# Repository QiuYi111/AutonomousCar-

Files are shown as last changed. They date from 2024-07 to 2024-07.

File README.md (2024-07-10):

# 机电系统设计实践

Openmv 官方中文教程 https://book.openmv.cc/

STM32教程https://ucbeginner.com/stm32cubeide/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,Best%20Practices%20...%208%20Troubleshooting%20...%20More%20items

git 官方中文教程 https://git-scm.com/book/zh/v2

STM32 油管系列教程
STM32教程 (https://www.youtube.com/watch?v=Hffw-m9fuxc "STM32教程")

电气原理图绘制工具 https://www.diagrams.net/index.html

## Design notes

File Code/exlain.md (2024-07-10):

好的，这段代码主要实现了通过OpenMV相机进行目标检测和跟踪，并通过UART串口与STM32单片机通信，以实现控制LED灯、舵机和其他功能。以下是这段代码的详细中文解释：

### 导入模块
```python
import sensor, image, time, math, pyb, time
from pyb import LED, UART, Servo, Pin, Timer
import json
import ustruct
```
这些模块用于控制传感器、处理图像、计时、数学计算、控制硬件等。

### 初始化UART串口
```python
uart = UART(3,115200)   # 定义串口3变量
uart.init(115200, bits=8, parity=None, stop=1) # 使用给定参数初始化
```
初始化UART串口，用于与STM32单片机通信。

### 初始化全局变量
```python
rx_buff = []
state = 0
MODE = 0
rx_buff1 = []
state1 = 0
is_fetch1 = 0
red_led = LED(1)
```
这些全局变量用于串口通信的数据缓冲、状态和模式管理。

### 初始化LED灯
```python
led1 = pyb.LED(1)
led2 = pyb.LED(2)
led3 = pyb.LED(3)
```
初始化三个LED灯，用于指示系统状态。

### 串口接收函数
```python
def Receive_Prepare1(data):
    global state
    global MODE
    if state == 0:
        if data == 0xb3:
            state = 1
        else:
            state = 0
            rx_buff.clear()
    elif state == 1:
        MODE = data
        print(MODE)
        state = 2
    elif state == 2:
        if data == 0xb4:
            state = 3
    else:
        state = 0
        rx_buff.clear()
```
这个函数用于处理串口接收到的数据，根据接收到的字节调整状态和模式。

```python
def Receive_Prepare2(data1):
    global state1
    global is_fetch1
    if state1 == 0:
        if data1 == 0xa0:  # 帧头0xb3
            state1 = 1
        else:
            state1 = 0
            rx_buff1.clear()
    elif state1 == 1:
        is_fetch1 = data1
        print(is_fetch1)
        state1 = 2
    elif state1 == 2:
        if data1 == 0xa1:  # 0xb4
            state1 = 3
        else:
            state1 = 0
            rx_buff1.clear()
```
这个函数处理另一种串口数据，用于不同的状态和数据处理。

### 主循环
```python
mode = 2
while(True):
    red_led.on()
    if MODE == 0:  # 等待STM32发送指令
        if (uart.any() > 0):
            c = uart.readchar()
            Receive_Prepare1(c)
            print(MODE)
```
这是主循环，控制不同模式下的操作。当`MODE`为0时，等待STM32发送指令。

### 循迹模式
```python
    if MODE == 1:  # 循迹部分
        print('MODE==1')
        if mode == 2:
            sensor.reset()  # 初始化摄像头传感器
            sensor.set_pixformat(sensor.RGB565)
            sensor.set_framesize(sensor.QQVGA)
            sensor.skip_frames(10)
            sensor.set_auto_gain(False)  # 颜色跟踪必须关闭自动增益
            sensor.set_auto_whitebal(False)  # 颜色跟踪必须关闭白平衡
            clock = time.clock()
            # a=0
            # 串口接收函数2
            # rx_buff=[
```
当`MODE`为1时，进入循迹模式，初始化摄像头传感器和一些图像处理设置。

```python
            while(mode == 2):
                def find_max(blobs):
                    max_size = 0
                    for blob in blobs:
                        if blob.pixels() > max_size:
                            max_blob = blob
                            max_size = blob.pixels()
                    return max_blob  # 寻找最大色块并返回最大色块的坐标
                img = sensor.snapshot().lens_corr(strength = 1.8, zoom = 1.0)
                wuti_threshold = (0, 100, 9, 127, 0, 127)
                blobs = img.find_blobs([wuti_threshold])
                if blobs:
                    max_blob = find_max(blobs)
                    img.draw_rectangle(max_blob.rect())  # 框选最大色块
                    img.draw_cross(max_blob.cx(), max_blob.cy())  # 在最大色块中心画十字
                    pcx = max_blob.cx() - 79.5  # 定义pcx为最大色块中心的横坐标
                    pcy = 119 - max_blob.cy()
                    if pcy > 90:
                        dev_s1 = 90
                    else:
                        dev_s1 = pcy
                    if pcx < 0:
                        cy1 = 1
                    else:
                        cy1 = 0
                    cw1 = int(abs(pcx))
                    cx1 = int(abs(pcx * 10)) % 10
                    ch1 = int(dev_s1)
                    OUT_DATA1 = bytearray([0x2C, 0x12, cy1, cw1, cx1, ch1, 0x5B])
                    uart.write(OUT_DATA1)
                    # print(pcx)
                    print(pcy)
                else:
                    OUT_DATA2 = bytearray([0x2C, 0x12, 0, 9, 9, 90, 0x5B])  # 原地缓慢旋转
                    # print(OUT_DATA2)
                    uart.write(OUT_DATA2)
                    # print('not found!')
```
在这个循环中，摄像头捕捉图像并寻找符合阈值的色块，找到后框选最大色块并发送其坐标数据到STM32。

### 模式切换
```python
                if (uart.any() > 0):
                    cc = uart.readchar()
                    Receive_Prepare2(cc)
                if is_fetch1 == 1:
                    mode = 6
                    print('mode=6')
```
如果接收到特定数据，会切换模式。

### 其他模式处理
```python
        if mode == 3:
            LED(1).on()
            LED(2).on()
            LED(3).on()
            s1 = Servo(1)  # P7
            s1.angle(-30)
            sensor.reset()  # 重置并初始化传感器
            sensor.set_pixformat(sensor.GRAYSCALE)  # 设置像素格式为灰度图像
            sensor.set_framesize(sensor.QQVGA)  # 设置帧大小为QVGA (320x240)
            THRESHOLD = (80, 255)
            sensor.skip_frames(time=20)  # 等待设置生效
            clock = time.clock()  # 创建时钟对象以跟踪FPS
            comp = 0
            startsym = 1
            dist = 0
            chan = 0
            mark1 = 0
            mark2 = 0
            # mark3=0
```
不同的模式下，进行不同的初始化和处理，比如模式3中，初始化舵机、传感器等，并进行相应的图像处理和数据传输。

### 避障模式
```python
    elif MODE == 2:  # 避障部分
        if mode == 2:
            LED(1).on()
            LED(2).on()
            LED(3).on()
            sensor.reset()  # 初始化摄像头传感器
            sensor.set_pixformat(sensor.RGB565)
            sensor.set_framesize(sensor.QQVGA)
            sensor.skip_frames(10)
            # sensor.set_auto_whitebal(False)
            clock = time.clock()
            # 串口接收函数2
            rx_buff = []
            def Receive_Prepare2(data):
                global state
                global is_fetch
                if state == 0:
                    if data == 0xaa:  # 帧头0xb3
                        state = 1
                    else:
                        state = 0
                        rx_buff.clear()
                elif state == 1:
                    is_fetch = data
                    print(is_fetch)
                    state = 2
                elif state == 2:
                    if data == 0xdd:  # 0xb4
                        state = 3
                else:
                    state = 0
                    rx_buff.clear()
```
在避障模式下，摄像头捕捉图像并寻找红色阈值的色块，找到后框选最大色块并发送其坐标数据到STM32。

### 其他模式处理
代码中还包含了模式5和模式6的处理，这些模式下进行了不同的传感器初始化和图像处理，以实现不同的功能需求。

### 总结
这段代码通过OpenMV相机进行目标检测和跟踪，并通过UART串口与STM32单片机通信，来实现不同模式下

的功能，例如循迹、避障等。不同的模式下进行了不同的传感器初始化和图像处理，以实现特定的功能需求。

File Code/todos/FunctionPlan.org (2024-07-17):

* DONE MeasureDistance函数
** 参数
   + TIM_HandelDef 定时器
   + Trig 的port 和引脚号
   + Echo的port和引脚号
** 返回
   + uint16_t 障碍物距离信息。单位mm

* TODO imuTheta
** 参数
   +
** 返回
   + 偏航角信息

* TODO imuAcc
** 参数
   +
** 返回
   + 各方向加速度

* TODO motorController
** 参数
   + 指定轮速
   + KP,KI,KD
** 返回
   + void 控制PWM占空比

* TODO lineFollowing
**   
** 返回
   + 两轮差速

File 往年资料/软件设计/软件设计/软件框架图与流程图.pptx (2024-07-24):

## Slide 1

系统软件逻辑框图

执行模块

motor.h
motor.c
控制电机转速
读取电机参数

bluetooth.h
bluetooth.c
与外部设备交换数据
接收外部设备指令

imu.h
imu.c
获得小车当前方向与位置信息

sonic.h
sonic.c
控制超声波探测器测距
发送测得参数

control.h
control.c
PID计算与控制
电机速度设定
小车方向设定

main.c
主函数
收发/传输数据
接受/发出指令

servo.h
servo.c
控制舵机旋转
获得舵机转角

openmv.py
处理openmv感知到的图像
计算得出进一步指令需要的参数
发送参数（抓取物体位置、巡线等）

openmv.h
openmv.c
处理与openmv的数据通讯
与单片机传输openmv得到的参数与指令

信息采集模块

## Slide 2

巡线部分算法

openmv
拍摄图像

检测特定行中白色块数

二值化处理

2个
取中心点前进

非2个（0，1，3，4等）
根据前几次搜索结果进行偏移

滤波去噪

根据偏移量PID调速

调用卸货模块

搜索特定行

NO

检测是否到达终点

结 束

YES

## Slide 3

巡线软件逻辑框图

openmv.py
处理openmv感知到的图像
计算得出进一步指令需要的参数
发送参数（抓取物体位置、巡线等）

偏移量等路线信息

openmv.h
openmv.c
处理与openmv的数据通讯
与单片机传输openmv得到的参数与指令

main.c
主函数
收发/传输数据
接受/发出指令

control.h
control.c
PID计算与控制
电机速度设定
小车方向设定

motor.h
motor.c
控制电机转速
读取电机参数

设定转速等

传输数据

发送运动指令

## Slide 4

避障部分算法

开 始

利用超声传感器测距

检测是否小于规定距离

算法仿真如下

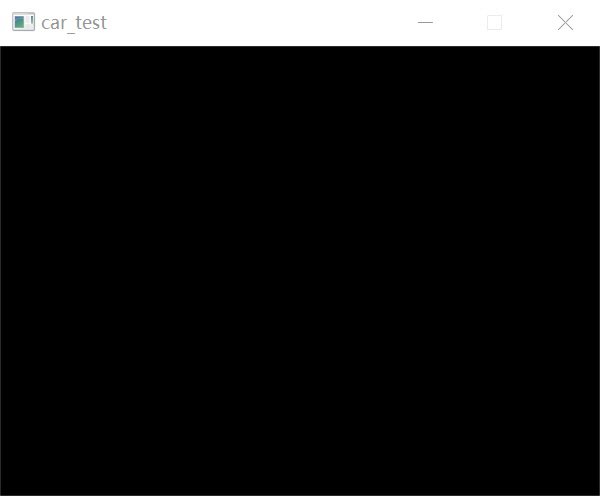
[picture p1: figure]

NO

YES

利用势场法确定新方向

检测是否到达终点

调用卸货模块

NO

结 束

YES

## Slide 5

避障软件逻辑框图

imu.h
imu.c
获得小车当前方向与位置信息

main.c
主函数
收发/传输数据
接受/发出指令

control.h
control.c
PID计算与控制
电机速度设定
小车方向设定

motor.h
motor.c
控制电机转速
读取电机参数

设定转速等

发送运动指令

sonic.h
sonic.c
控制超声波探测器测距
发送测得参数

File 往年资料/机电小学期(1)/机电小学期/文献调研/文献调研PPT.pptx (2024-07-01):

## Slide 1

机电系统设计实践课程初期汇报

机电系统初探

文献调研与初步方案

汇报人：荆尹浩宇 张佳悦 滕一铭

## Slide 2

目录

CONTENTS

01

车体结构

02

功能传感

03

驱动控制

04

电机电源

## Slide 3

PART 01

车体结构

·车架总体 ·抓取机构

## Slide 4

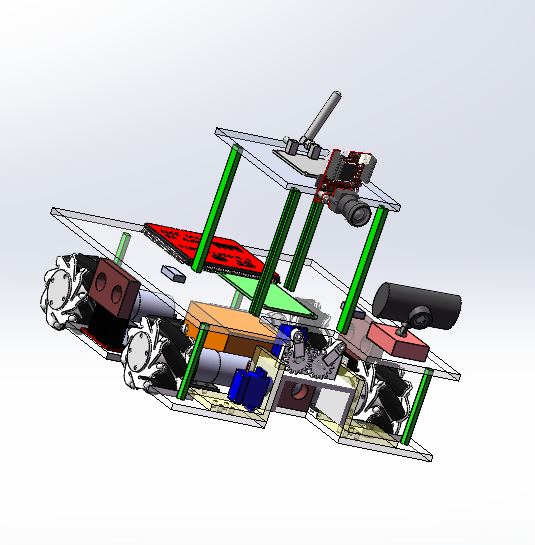
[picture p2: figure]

车架总体

车架整体尺寸需求：
在自助避障任务中，障碍物间的间距不小于350mm，因此，小车的宽度应小于350mm并留出适量裕度。

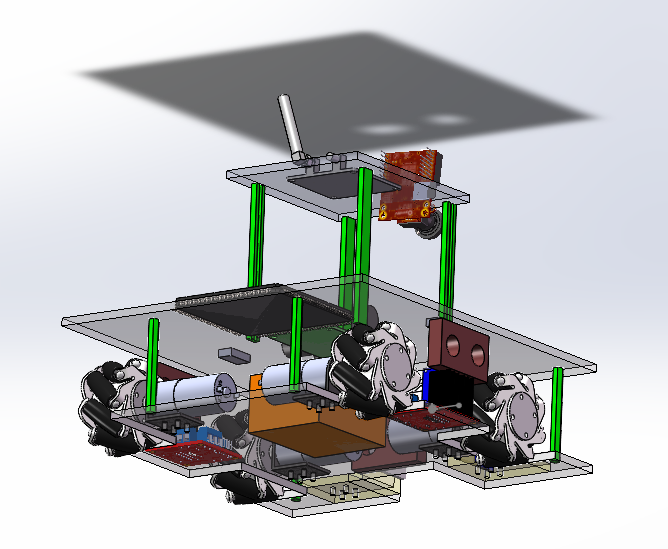
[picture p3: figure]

初步建模

由于小车的占地面积不能过大，且需要在车架上装配多种元器件和电子线路，因此可以考虑将小车做成 二层或三层结构。

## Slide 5

车架总体

轮式小车

节省空间、机动性好
承载重量大、结构简单
可控性强、安全性好

履带式小车

对地面单位压力小
行驶通过能力强
结构简单，结实耐用
适合在条件不好的环境下作业

步行式机器人

对地形适应性较强
对环境的破坏程度较小
运动的灵活性强
运动控制较为精确

A

B

C

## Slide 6

抓取机构

抓取机构尺寸需求：
货物直径30mm，高40mm，重50g。因此抓取装置的“钳爪”需要和货物尺寸匹配，同时要考虑抓取时的姿态，保证足够的压力与摩擦力，避免抓取过程中掉落。

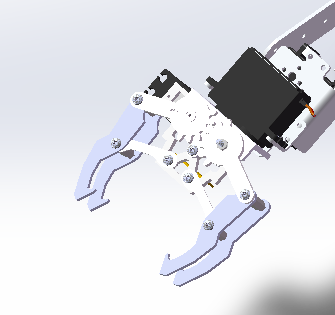
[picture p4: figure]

初步建模

考虑到取物前后图像识别的需要，以及超声波传感器的位置，需要使抓取结构尽量短小，且抓取后不能遮挡摄像头与传感器

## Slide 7

抓取机构

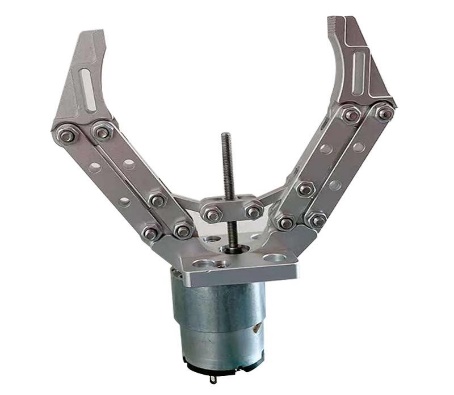
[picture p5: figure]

机械手爪

气动手爪结构简单，轻量化，但可靠性欠缺
液压手爪抓取力大，精确性高，成本高
电动手爪易于控制，但夹紧力较小

吸盘

磁力吸盘体积小，自重轻，实用场景广泛，但要求抓取的物品有磁性
真空吸盘原理简单，操作相对容易，但要求物体表面平整，对于维护保养的要求较高。

仿生多指灵巧手

操作能力、灵活性和快速反应能力非常强大，能够进行复杂的抓取作业
但成本也随之大大增加

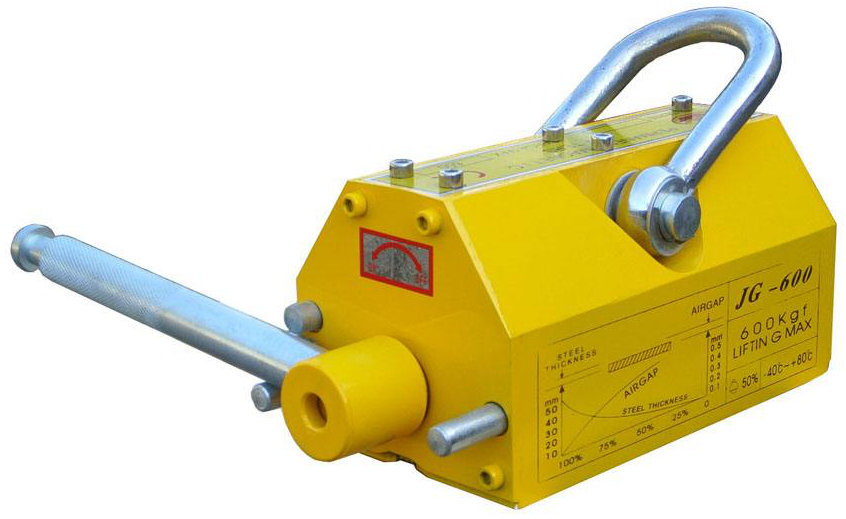
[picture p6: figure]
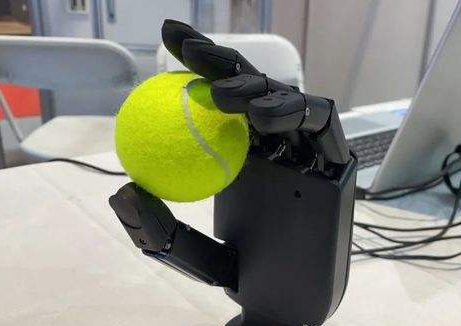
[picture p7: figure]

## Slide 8

PART 02

功能传感

·巡线部分 ·避障部分

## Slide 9

循线部分|避障部分

红外传感器

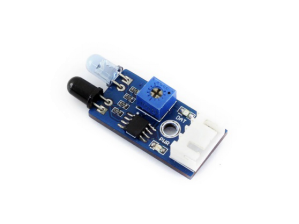
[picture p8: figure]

红外传感器

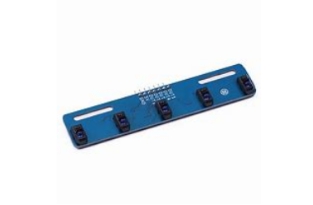
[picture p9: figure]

五路红外循迹模块

基本原理
红外发射管→发射红外线
红外接收管→接受红外线
光电传感器或灰度传感器→将光信号转化成电信号

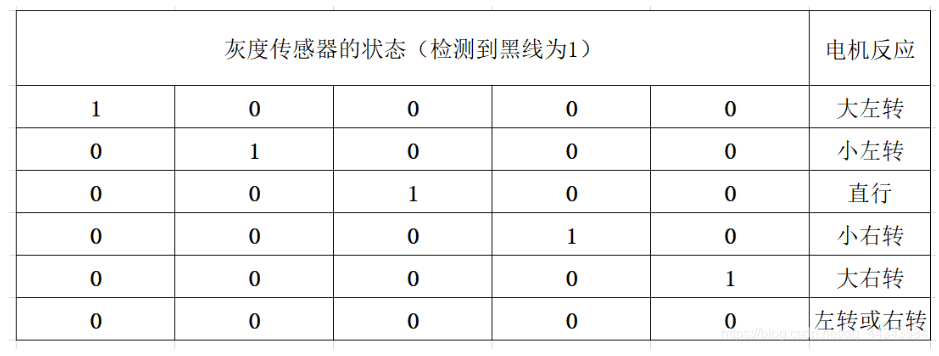
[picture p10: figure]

白色地面→红外线强→电信号强
黑色引线→红外线弱→电信号弱

红外传感器信号强弱→调整循迹

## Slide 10

循线部分|避障部分

红外传感器

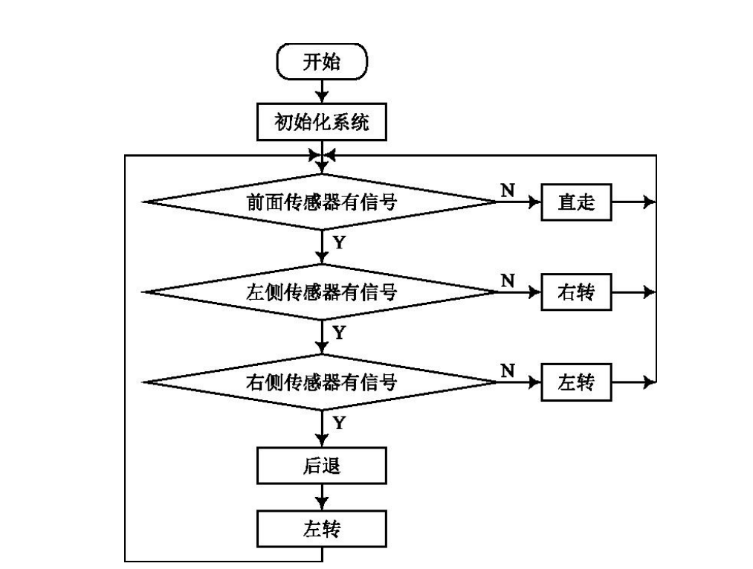
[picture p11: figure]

具体流程
先后判断前方、左侧、右侧传感器
决策是否直行、右转、左转
若三者均有信号，则小车前方为黑线
小车先后退再左转，继续循迹

性能比较
优点：灵敏度高、体积小、易于安装等
缺点：对道路的前瞻性不强，循迹效率不高

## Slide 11

循线部分|避障部分

线阵CCD

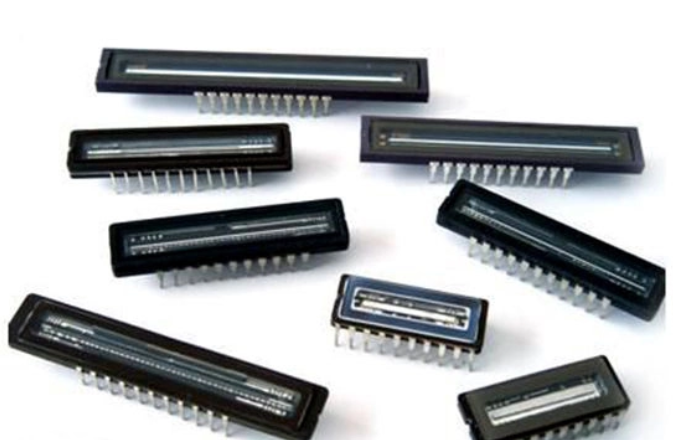
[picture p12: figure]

使用方法
在图像信息采集时,将单片机的端口与CCD的图像灰度信息输出引脚相连，采集得到图像灰度值，对灰度值进行二值化和滤波处理后,最终可以确定道路的情况

多重处理
滤波处理(时域滤波法)：平均值滤波、中值滤波、限值滤波与滑动平均值滤波
阈值求解(动态阈值法)：取平均电压值、最大值与最小值的均值、大津算法

性能比较
优点：路径分辨率高，前瞻性较强，可以实时监控路径的位置，及时纠偏
缺点：图像获取时间较长，测量效率较低，且图像精度可能受到扫描运动精度的影响

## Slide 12

循线部分|避障部分

处理方法
首先读取有效部分的灰度值并提取赛道信息。
获得赛道信息后，根据小车的具体偏移量利用PD控制算法来计算舵机的转角，再利用PID算法闭环调节小车的速度。

畸变矫正
由于摄像头与地面之间存在俯角,导致采集到的图像并不是方形区域,图像会出现失真，可以通过非均匀行采集的算法对畸变进行矫正。

性能特点
优点：可以获得二维的图像信息，前瞻性和纠偏能力优于线阵CCD
缺点：图像分辨率低于线阵CCD

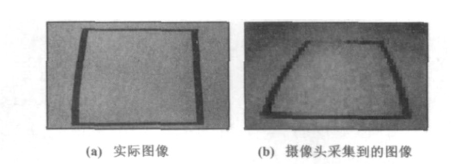
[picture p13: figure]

摄像头

梯形失真示意图

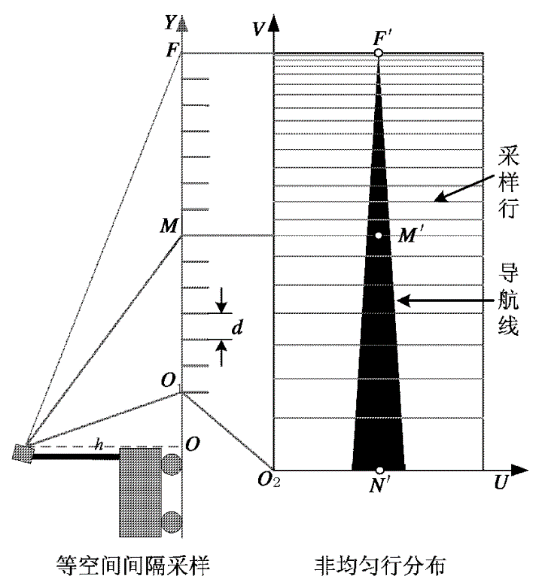
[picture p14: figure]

非均匀行采样示意图

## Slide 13

循线部分|避障部分

初步选定方案

更强的前瞻能力

线阵CCD

OpenMV

摄像头

更多的资源
更强大的功能

更强的纠偏能力
更短的图像获取时间

红外传感器

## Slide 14

循线部分|避障部分

红外避障传感器

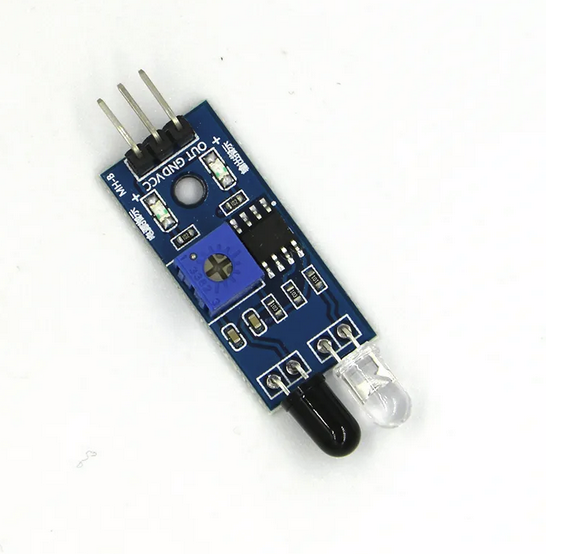
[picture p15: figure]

基本原理
红外避障传感器主要以红外测距传感器为主。红外测距都是采用三角测距的原理

适用范围
有效距离范围为0-20cm,可以通过电位器旋钮调节探测距离，广泛应用于避障小车、流水线计数等场合

性能比较
优点：结构简明，便于装配，成本低廉，反应灵敏且抗干扰能力强
缺点：检测距离和精度有限，传感器高度位置的差异可能会对其检测造成干扰

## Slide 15

循线部分|避障部分

超声波避障传感器

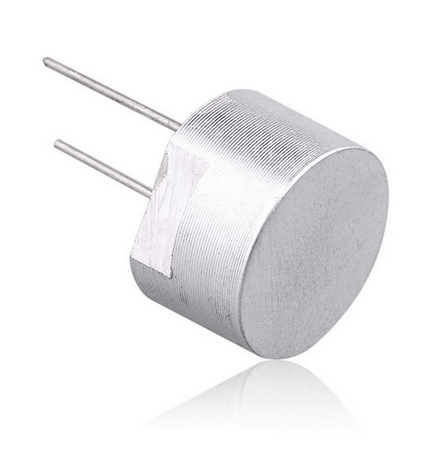
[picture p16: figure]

基本原理
主要通过发射到接收声波的时间差计算出测量距离

适用范围
有效距离范围一般在5-10m，但会存在一个最小探测盲区，一般在几十毫米，它常用于移动机器人，AGV，无人机，汽车避障

性能比较
优点：结构简单，制造方便，成本较低，不易受恶劣天气及环境电磁场的干扰
缺点：测距速度不如激光测距和毫米波测距，且只能测量距离，不可以测量方位

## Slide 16

循线部分|避障部分

激光雷达传感器

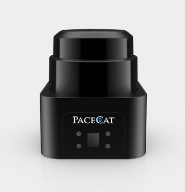
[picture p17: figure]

基本原理
主要通过接收和反射之间的时间间隔确定到目标的距离，通过几何变换激光束角度获得对象位置的信息

适用范围
三角波测距原理的激光雷达探测距离只有几米，而TOF法测距距离可达几百米

性能比较
优点：探测范围更广，探测精度更高，可以获取比较致密的点云信息
缺点：受环境影响大且无穿透能力，价格较为昂贵

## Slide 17

循线部分|避障部分

毫米波雷达传感器

基本原理
主要通过检测发出波形与返回波形之间差拍频率的高低计算时延长度进而判断传感器到障碍物的距离

适用范围
探测距离较长,可以达到200多米，它广泛应用于导弹制导、目标监视和截获、炮火控制和跟踪和雷达测量等方面

性能比较
优点：探测距离远、可靠性高、受环境影响较小
缺点：毫米波在高潮湿环境会有所衰减，且价格也较为高昂

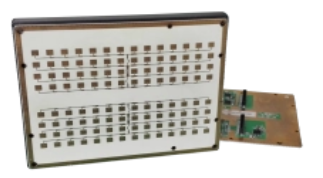
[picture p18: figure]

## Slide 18

循线部分|避障部分

摄像头及图像处理

基本原理
具体的提取有效部分图像、扫描灰度值、获得附近区域信息及畸变矫正的过程均与循迹部分相同，在摄像头角度与处理图像上有所不同

适用范围
探测距离与具体型号有关，也广泛应用于无人机避障、小车避障等方面

性能比较
优点：可以获得二维的图像信息，有较好的前瞻性
缺点：不适用于要求视场大、图像分辨率高的情形

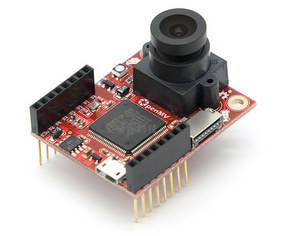
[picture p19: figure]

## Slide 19

循线部分|避障部分

算法比较

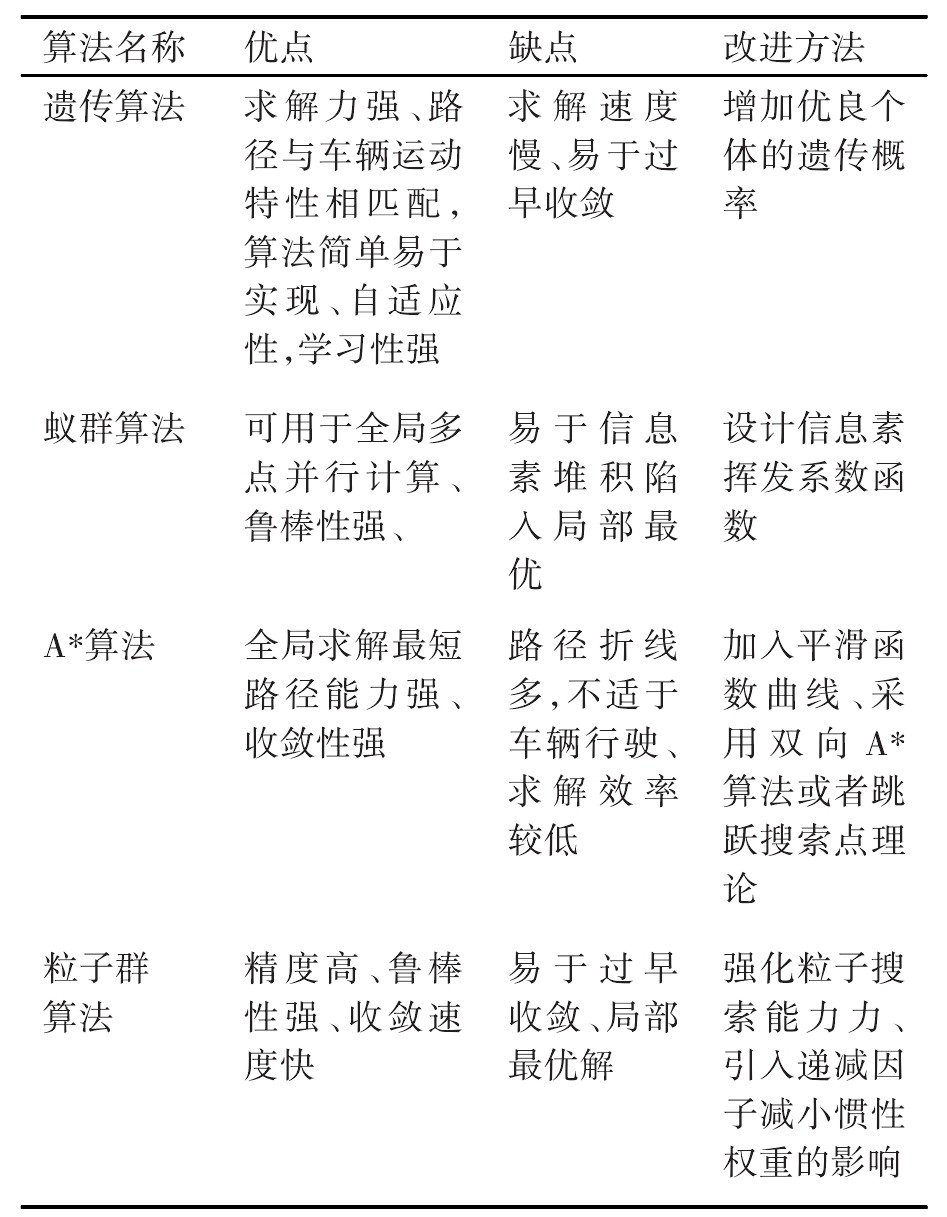
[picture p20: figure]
JCGC202205004_03000(2)

全局路径规划算法的优缺点
以及其改进方式

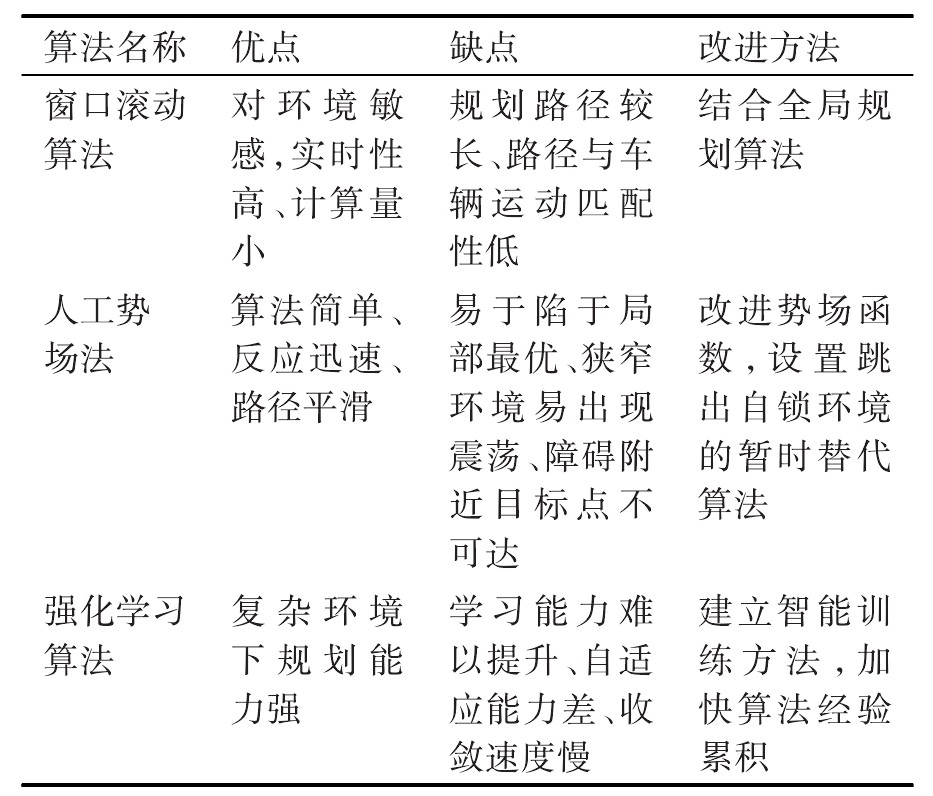
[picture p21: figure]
JCGC202205004_04400(3)

局部路径规划算法的优缺点
以及其改进方式

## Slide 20

PART 03

驱动控制

·驱动方式 ·转向方式 ·控制器硬件 ·数据通讯

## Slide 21

驱动方式

两驱

四驱

前驱或者后驱由于驱动电机数量少
空间利用率高
轻量化、耗能低
操控性差，转向时易打滑

四驱小车四轮均能够获得动力
前后配重相对均匀，操控性更好
适应路面能力强
导致小车自重较大，耗能高

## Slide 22

转向方式

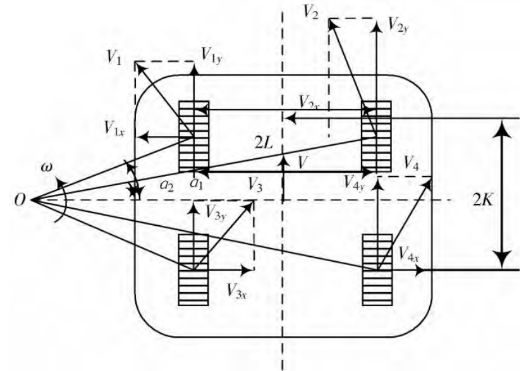
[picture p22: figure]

麦克纳姆轮

麦克纳姆轮移动平台具有平面上3个自由度的移动能力。它依靠4个轮子各自转速的配合来实现全向移动。
与轮子的轴线呈45度的辊子自由转动，这使得轮子只受到地面对辊子轴向上的力。通过不同受力情况的组合，得到三个自由度的不同速度。

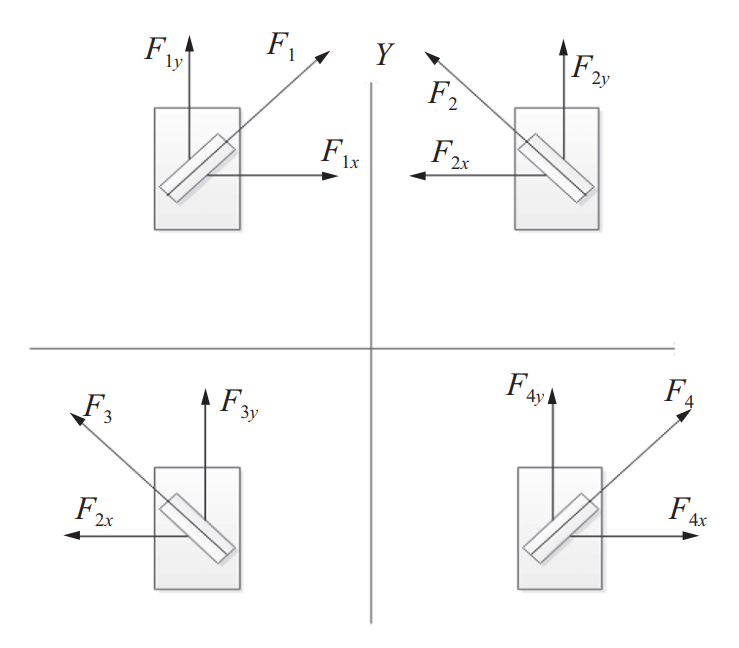
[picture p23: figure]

普通轮（差速法）

参考阿克曼转向几何学原理，即在汽车转向时4个轮胎都近似围绕一个中心点旋转以保证汽车的行驶稳定性。
通过控制内测轮与外侧轮的不同速度来实现不同的曲率半径，从而实现转向。

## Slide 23

控制器硬件

需求分析：
PWM控制电机
图像识别
信号处理
串行通信

stm32

openMV

其他方式

树莓派

FPGA

PPT模板 http://www.1ppt.com/moban/

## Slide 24

数据通讯

需求分析：考虑到小车需要进行远程无限通信与控制，因此需要寻找无线通讯的手段

蓝牙模块体积很小、便于集成，功耗低，具有很好的抗干扰能力，在短距离传输场景下较为可靠。蓝牙透传的通信速率较低。
可以选用的HC-05模块具备全双工模式，可以实现在发送运行数据的同时接受来自手机的控制信号。

近年来才兴起的无线网络通信技术标准，拥有低功耗、低成本、短时延、安全性高等等优点，支持多节点之间的通信，但是传输速率较低

WiFi与蓝牙技术一样同属于短距离无线技术，拥有覆盖范围广，无需布线，传输速度快的优势，在当前的移动终端的联网方面应用广泛，但透传的WiFi串口协议速率容量相对较低。

蓝牙

Zigbee

WiFi

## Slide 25

PART 04

电机电源

·电机与驱动 ·总电源与二次电源

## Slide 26

电机与驱动

需求分析：车轮运动、抓取机构转向、抓取目标

航模舵机
•较高精度角度控制，自闭环控制，应用简单
直流电机
•适合连续旋转，电流驱动器+控制器角度与速度控制，复杂
永磁同步电机：
•适合长行程精密运动系统的直接出力
音圈电机
•适合微行程精密运动系统
步进电机
•适合开环较高精度控制
交流异步电机
•变频驱动器+速度控制，大力矩时适合与减速器共同使用智能车应用较多

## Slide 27

电源与二次电源

需求分析：提供各个模块不同的工作电压

25GA370直流电机 12V
STM32F103单片机 5V
HC-05蓝牙串口模块 5V
L298N电机驱动模块 5V
OpenMV图像处理模块 5V
HC-SR04超声波传感器 5V
SG90舵机 5V
MG995舵机 5V

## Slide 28

感谢观看

文献调研与初步方案

汇报人：荆尹浩宇 张佳悦 滕一铭

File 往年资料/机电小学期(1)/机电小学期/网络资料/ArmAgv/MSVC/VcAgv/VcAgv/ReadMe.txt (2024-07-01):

================================================================================
    MICROSOFT 基础类库 : VcAgv 项目概述
===============================================================================

应用程序向导已为您创建了此 VcAgv 应用程序。此应用程序不仅演示 Microsoft 基础类的基本使用方法，还可作为您编写应用程序的起点。

本文件概要介绍组成 VcAgv 应用程序的每个文件的内容。

VcAgv.vcxproj
    这是使用应用程序向导生成的 VC++ 项目的主项目文件，其中包含生成该文件的 Visual C++ 的版本信息，以及有关使用应用程序向导选择的平台、配置和项目功能的信息。

VcAgv.vcxproj.filters
    这是使用“应用程序向导”生成的 VC++ 项目筛选器文件。它包含有关项目文件与筛选器之间的关联信息。在 IDE 中，通过这种关联，在特定节点下以分组形式显示具有相似扩展名的文件。例如，“.cpp”文件与“源文件”筛选器关联。

VcAgv.h
    这是应用程序的主头文件。
    其中包括其他项目特定的标头（包括 Resource.h），并声明 CVcAgvApp 应用程序类。

VcAgv.cpp
    这是包含应用程序类 CVcAgvApp 的主应用程序源文件。

VcAgv.rc
    这是程序使用的所有 Microsoft Windows 资源的列表。它包括 RES 子目录中存储的图标、位图和光标。此文件可以直接在 Microsoft Visual C++ 中进行编辑。项目资源包含在 2052 中。

res\VcAgv.ico
    这是用作应用程序图标的图标文件。此图标包括在主资源文件 VcAgv.rc 中。

res\VcAgv.rc2
    此文件包含不在 Microsoft Visual C++ 中进行编辑的资源。您应该将不可由资源编辑器编辑的所有资源放在此文件中。

/////////////////////////////////////////////////////////////////////////////

应用程序向导创建一个对话框类：

VcAgvDlg.h、VcAgvDlg.cpp - 对话框
    这些文件包含 CVcAgvDlg 类。此类定义应用程序的主对话框的行为。对话框模板包含在 VcAgv.rc 中，该文件可以在 Microsoft Visual C++ 中编辑。

/////////////////////////////////////////////////////////////////////////////

其他功能：

ActiveX 控件
    该应用程序包含对使用 ActiveX 控件的支持。

Windows 套接字
    应用程序包含对通过 TCP/IP 网络建立通信的支持。

/////////////////////////////////////////////////////////////////////////////

其他标准文件:

StdAfx.h, StdAfx.cpp
    这些文件用于生成名为 VcAgv.pch 的预编译头 (PCH) 文件和名为 StdAfx.obj 的预编译类型文件。

Resource.h
    这是标准头文件，可用于定义新的资源 ID。Microsoft Visual C++ 将读取并更新此文件。

VcAgv.manifest
	Windows XP 使用应用程序清单文件来描述特定版本的并行程序集的应用程序依赖项。加载程序使用这些信息来从程序集缓存中加载相应的程序集，并保护其不被应用程序访问。应用程序清单可能会包含在内，以作为与应用程序可执行文件安装在同一文件夹中的外部 .manifest 文件进行重新分发，它还可能以资源的形式包含在可执行文件中。
/////////////////////////////////////////////////////////////////////////////

其他注释:

应用程序向导使用“TODO:”来指示应添加或自定义的源代码部分。

如果应用程序使用共享 DLL 中的 MFC，您将需要重新分发 MFC DLL。如果应用程序所使用的语言与操作系统的区域设置不同，则还需要重新分发相应的本地化资源 mfc110XXX.DLL。
有关上述话题的更多信息，请参见 MSDN 文档中有关重新分发 Visual C++ 应用程序的部分。

/////////////////////////////////////////////////////////////////////////////

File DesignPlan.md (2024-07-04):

# Table of Contents

1.  [选型](#org84336b8)
    1.  [车体：](#orgad3df49)
    2.  [循迹：](#org96ccd5c)
    3.  [避障：](#org2c3c491)
    4.  [信息回传：](#orgf15e68a)
    5.  [硬件：](#orgb132868)

[机电系统设计实践](机电系统设计实践-20240701080755.md)

# 设计

## 车体：(待定)

-   车型：三轮
-   夹取机构：夹子（juny）

## 测量（juny）

## 循迹(jingy)：

-   PID
-   传感：视觉

## 避障(jh)：

-   地图：SLAM
-   算法：人工势场

## 信息回传：

-   蓝牙模块(jingyi jh)
-   ui界面

## 硬件和驱动（jingy jh）：

-   给定的单片机
-   GPU
-   传感器：
    -   1个摄像头
    -   3各激光雷达
    -   里程计
    -   蓝牙
- 电机 （jh）：
    -   双驱动
    -   3个编码器
    -

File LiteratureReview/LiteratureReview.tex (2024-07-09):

%%%%%%%%%% Conference Latex Template for the university center of Tipaza - Algeria
%%%%%%%%%% created by F.CHABNI

\documentclass{report}
\usepackage{ctex}
\usepackage{geometry}
\usepackage{graphicx}
\usepackage{amsmath}
\usepackage{cite}
\usepackage{subcaption}
\usepackage{booktabs}
\usepackage{multirow}
% \usepackage{graphicx}
\usepackage[table,xcdraw]{xcolor}
\title{自主移动车文献综述和原型设计}
\author{邱璟祎, 周俊豪, 张峻瑜\\
  （按姓名首字母排序）
}
\geometry{a4paper,scale=0.8}
\begin{document}
\maketitle
\tableofcontents
\newpage
\chapter{引言}

在当今这个技术飞速发展的时代，自动化和智能化已成为工业生产和日常生活的关键趋势。在自动化物流系统中，智能小车扮演着核心角色，其发展和应用吸引了广泛的关注。本研究旨在响应这一时代的需求，设计并开发一款AGV智能小车。本文将从课程任务出发，对各个任务模块进行细致分析和分解，通过文献综述梳理现有解决方案，并提出一个初步的设计方案。

本文所探讨的智能小车是一种能够在自动导引车（AGV）系统中自主完成移动、货物抓取、运输和卸载的自动化设备。在对智能小车的需求进行深入分析和任务分解后，本文将从机械设计、路径追踪算法和避障策略三个关键技术领域进行详尽的文献调研，并进行综合性评述。我们将总结这些领域的现有技术，并评估它们在智能小车设计中的潜力和局限性。

在广泛调研的基础上，本文将结合需求分析和文献综述的结果，提出一套创新的设计方案。该方案将涵盖智能小车的机械结构、测量技术、路径追踪与避障算法、数据传输和驱动系统等关键技术要素。同时，本文也将探讨该方案的实施可行性及其可能面临的技术挑战。

通过本研究，我们期望为智能小车的设计提供有价值的参考和指导，为智能小车市场的设计提供新的思路，促进自动化物流技术的发展，并为工业自动化和智能运输系统的创新贡献力量。

\chapter{需求分析}
课程任务为：设计并实现一个机电系统，按照规定路线，在2种不同场地，将指定物品从一个指定位置运输到另一指定位置。两种场地分别需要实现循迹和避障的功能。为了完成这个任务，将任务分解为机械结构、电气、测量、算法和系统软件五个方面的内容。
\section{机械结构}
\label{sec:label}
\subsection{车体结构}
\label{subsec:label}
\begin{enumerate}
\item 整体尺寸：避障部分场地的障碍物间距不小于350mm，故小车的整体尺寸应当小于该距离。
\item 驱动与转弯方式：驱动方式可以选择轮式或者履带式，转弯方式可以采用差速转向或者麦克纳姆轮转向。
  \item 车体空间结构：车上需要装载驱动电机、控制板、传感器等元件以及电子线路，可以考虑设计多层结构，同时需要考虑重心的稳定性和小车的承重性能。
\end{enumerate}
\subsection{抓取机构}
\label{subsec:label}
\begin{enumerate}
\item 机械爪及舵机：货物尺寸为直径30mm，高40mm，其重量为50g，因此抓取结构中的机械爪需与货物尺寸相匹配，且相应舵机需要有足够的力矩。
  \item 抓取结构大小与工作空间：因小车本身体积有限，因此抓取结构不应过大。除此之外，还需考虑抓取结构的工作空间，如不能遮挡摄像头视野等。
  \end{enumerate}
  \newpage
\section{电气}
\label{subsec:label}
\subsection{控制器硬件}
\label{subsec:label}
常用的包括编程调试方便，主要串行执行的CPU和并发速度快，可靠性好，调试困难的FPGA，可以根据功能需求、计算能力等方面的约束进行选取。
\subsection{电机与驱动}
\label{subsec:label}
常用的驱动电机包括航模电机和直流电机等，需要根据驱动力要求、电路负载要求等进行选取。
\subsection{电源}
\label{subsec:label}
单片机、电机、舵机等不同元器件的所需电压不同，需要进行相应的电源与二次电源的选择，具体选择将在原理方案设计部分确定。
\subsection{通讯}
\label{subsec:label}
需要实现的数据通讯任务包括实时图像、指令数据、状态参数和舵机命令等，可以采用USB数据线的有线通讯方式或者蓝牙等无线通讯方式，具体选择需要根据传输数据量、数据传输延时和硬件接口等因素确定。
\section{测量}
\label{sec:label}
需要传感器传回的信息主要包括图像灰度、距离、小车自身的位置和姿态等等，可能需要红外传感器、超声传感器、线阵CCD传感器、里程计和陀螺仪等，需要根据需求进行选取，同时要和车体结构相匹配。
\section{算法}
\label{sec:label}
循迹和避障的算法现有的文献和其他资料都有很多内容，将在后面文献综述部分加以阐述，并在设计部分进行选择。

\section{系统软件}
\label{sec:label}
系统软件需要根据功能和算法进行划分，并且和实际硬件进行对应，从而实现各个模块之间的交互。

\chapter{自主移动车文献综述}
\label{sec:label}

\section{机械设计研究综述}
\subsection{运动方式}
\label{subsec:label}
目前自主移动车的运动方式主要分为轮式和履带式，下面将分别论述这两种方式的特点。
\subsubsection{轮式运动}
\label{subsec:label}
轮式运动是自主移动车辆（Autonomous Mobile Vehicles, AMVs）中普遍采用的一种驱动方式，其核心功能是通过一个或多个轮子实现车辆的移动。这种设计可以采用标准的轮胎或灵活的全方位轮（Omni-Directional Wheels, ODWs），特别适合在平坦且结构简单的环境条件下使用。轮式驱动的优势在于其高度的机动性、简化的结构设计、强大的操控性能以及卓越的安全特性。

根据驱动机制的不同，轮式运动车辆可以被进一步分类为单驱动轮、双驱动轮和多驱动轮三种类型。单驱动轮系统通常应用于三轮的自动引导车（AGV），而双驱动轮系统则多见于四轮AGV。这两种驱动方式的共同之处在于，仅部分车轮配备驱动力，从而减少所需的驱动电机数量，降低车辆的总重量，并节省宝贵的内部空间。然而，这种设计有时可能导致由于重量分布不均，非驱动轮一侧的附着力不足，进而影响车辆的转向性能。

与此相对，多驱动轮AGV的每个轮子都与驱动电机相连，这提供了更强的驱动力和更均匀的重量分布。尽管如此，这种设计在提升驱动性能的同时，可能会在一定程度上降低车辆的灵活性。

\subsubsection{履带式运动}
\label{subsec:label}
采用履带驱动的自动引导车（AGV）因其独特的设计，在复杂地形如雪地和斜坡上展现出卓越的附着力和稳定性。这些AGV的地面压力较低，摩擦系数较高，使其能够承载较重的载荷。然而，与轮式AGV相比，履带式AGV的制造成本较高，且运行速度相对较慢。

履带式AGV的设计允许它们在承受重载的同时，在不平坦或恶劣的地面条件下保持稳定。它们的履带结构提供了较大的接触面积，这不仅减少了对地面的压力，还增加了与地面的摩擦力，从而提高了车辆的牵引力。虽然在成本和速度方面，履带式AGV可能不如轮式AGV，但它们在特定应用场景下的优势是无可替代的。

\newpage
\subsection{转向方式}
\label{subsec:label}
目前已有的AGV中，转向方式大部分都可以归结为差速转向和麦克纳姆轮转向两大类，下面将分别进行叙述
\subsubsection{差速转向\cite{chasu}}
\label{subsec:label}
在车辆设计中，采用四轮驱动系统并结合阿克曼转向几何学原理，可以显著提高车辆在转向时的稳定性和操控性。当车辆的前轮和后轮均具备驱动能力时，根据阿克曼原理，车辆在转向过程中，四个轮胎似乎围绕一个共同的中心点旋转，这种设计有助于保持车辆行驶的稳定性。

将车辆的几何中心视为质心，并在理想条件下忽略诸如路面条件变化等外部因素，我们可以构建一个四轮驱动且具有差速转向功能的小车的运动学模型。这一模型不仅能够描述车辆在直线行驶和转向时的运动特性，还能够为车辆控制系统的设计提供理论基础。

运动学模型的建立通常涉及对车辆动力学的简化和抽象，通过数学表达式来描述车辆的运动状态。在示意图中，我们可以清晰地看到车辆的转向机制和各轮子的相对位置，这有助于我们更好地理解车辆在不同转向条件下的运动规律。

\begin{figure}[ht]
  \centering
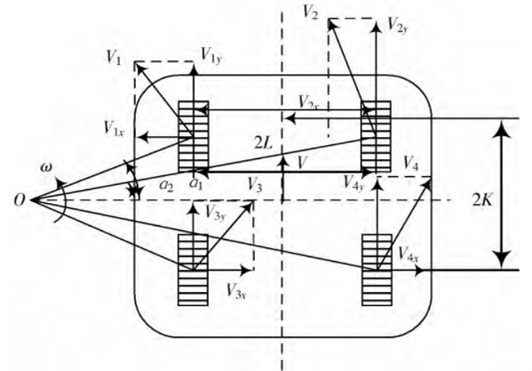
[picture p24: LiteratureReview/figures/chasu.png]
  
  \caption{差速转向受力分析}
\end{figure}
\newpage
$\alpha_1$和$\alpha_2$分别为前左轮和后左轮，前右轮和右轮的转角；2L 为左右轮距离； 2K 为前后轮轴距；$v$和$\omega$分别为车子质心的线速度和角速度，$V_1,V_2,V_3,V_4$分别为各个轮中心的实际运动方向。由图 可以得出各速度和转角的关系:
\[\begin{gathered}
V_{1}=\omega R_{1}=\omega\frac{K}{sin\alpha_{1}}\\
V_{2}=\omega R_{2}=\omega\frac{K}{sin\alpha_{2}} \\
V_{3}=V_{1}=\omega\frac{K}{sin\alpha_{1}} \\
V_{4}=V_{2}=\omega\frac{K}{sin\alpha_{2}}\\
V_{1y}=V_{1}cos\alpha_{1}= \omega\frac{K}{tan\alpha_{1}}=\omega(R-L)\\
V_{2y}=V_{2}cos\alpha_{2}= \omega\frac{K}{tan\alpha_{2}}=\omega(R+L)\\
V_{3y}=V_{3}cos\alpha_{1}= \omega\frac{K}{tan\alpha_{1}}=\omega(R-L)\\
V_{4y}=V_{4}cos\alpha_{2}= \omega\frac{K}{tan\alpha_{2}}=\omega(R+L)
\end{gathered}\]
式中$R=\frac v\omega $。

则电机的角速度为：$\omega_n=\frac{V_{ny}i}r,n=1,2,3,4$

式中$i$为减速器的减速比，$r$为车轮半径。

\subsubsection{麦克纳姆轮转向\cite{mac}}
\label{subsec:label}
麦克纳姆驱动系统赋予移动平台在二维平面内沿三个独立方向移动的能力。这一系统通过四个独立控制的轮子实现，每个轮子以不同的速度旋转，协同工作以提供全向移动的能力。每个轮子对整体移动方向和速度的贡献都是至关重要的。

与传统轮子不同，麦克纳姆轮的特点是其圆周上均匀分布着多个小型辊子，这些辊子的轴线与轮子中心轴线形成特定角度，如45度。这些辊子的轮廓线与轮子的基本圆形轮廓相匹配，确保了它们始终与地面保持接触。这些辊子能够自由旋转，使得轮子主要承受垂直于地面的力，而地面对辊子的摩擦力则转化为滚动摩擦，其影响可以忽略不计。

由于这种设计，轮子与地面的接触不是沿着轮子的圆周，而是以一定角度作用。这允许轮子在受到驱动力的同时，在另一个方向上实现自由移动。通过这四个轮子的协同作用，可以产生多种不同的受力情况，从而使平台能够在二维空间内沿三个方向自由移动。

用$R$表示全向轮轴心到轮外廓圆周面的距离即轮的半径；$V_i$表示第$i$轮的速度；$\alpha$表示辊子轴线与全向轮轴线夹角；$\omega_i$表示全向轮绕轮轴的转速；i=1,2,3,4,分别代表左前轮、右前轮、左后轮、右后轮。联立可得矩阵方程:
\[ V_i=\begin{pmatrix}R\\4\end{pmatrix}\begin{bmatrix}1&1&1&1\\\tan\alpha&-\tan\alpha&-\tan\alpha&\tan\alpha\\-\frac{1}{l_0}&\frac{1}{l_0}&-\frac{1}{l_0}&\frac{1}{l_0}\end{bmatrix}\begin{bmatrix}\omega_1\\\omega_2\\\omega_3\\\omega_4\end{bmatrix}\]

式中$l_0=$W+ Lcos$\alpha$,其中 W 为移动平台宽度，L 为其前后轮轴距；而$\alpha$取
$45^{\circ}$,其正负号已被提出，不再区分正负。逆运动学方程为:
\[\begin{bmatrix}\omega_1\\\omega_2\\\omega_3\\\omega_4\end{bmatrix}=\text{K}\begin{bmatrix}V_y\\V_x\\\omega\end{bmatrix}=\begin{pmatrix}\frac{1}{R}\end{pmatrix}\begin{bmatrix}1&cot\alpha&-l_0\\1&-cot\alpha&l_0\\1&-cot\alpha&-l_0\\1&cot\alpha&l_0\end{bmatrix}\begin{bmatrix}V_y\\V_x\\\omega\end{bmatrix}\]
总的来说，麦克纳姆轮转向具有高效率、高灵活性的特点。
\begin{figure}[ht]
  \centering
  
  \caption{麦克纳姆轮受力分析 }
\end{figure}
\subsection{抓取机构}
\label{subsec:label}
机械臂末端的抓取机构可以采用机械手爪、吸盘和仿生结构三种形式，它们具体的特点如下：
\subsubsection{机械手爪}
\label{subsec:label}
机械手爪的分类基于其驱动原理，可分为五大类：气动型、电动型、液压型、电磁型和热能型。气动型机械手爪利用压缩空气实现其抓取动作，其优点在于成本效益高和响应速度快，但需持续供应压缩空气，且在控制精度上存在局限。电动型机械手爪以电动机为动力源，通过齿轮、皮带或丝杠等机械传动元件传递动力，具有高精度控制和均衡的力矩输出，但可能因结构复杂性而增加成本。液压型机械手爪通过液压系统提供的动力进行操作，适合于承载较重的负载，但需要相应的液压泵和管道，维护成本较高。电磁型机械手爪利用电磁铁产生的磁力来驱动，具有快速响应和结构简洁的特点，但力量输出可能受限于磁场强度。热能型机械手爪则利用热膨胀原理进行操作，适用于软性材料的抓取，但反应速度较慢，应用场景相对有限。

\newpage
\subsubsection{吸盘}
\label{subsec:label}
吸盘主要分为两大类：磁力型和真空型。磁力吸盘以其小巧轻便、吸力强劲而著称，特别适用于钢铁、机械加工、模具制造和仓储物流等领域，对于搬运和吊装块状或圆柱形的磁性金属材料非常有效，能够显著提升装卸和搬运作业的效率。然而，它对被吸附物体的磁性特性有一定的要求。

另一方面，真空吸盘的工作原理较为直观，操作起来也相对简便。它的使用前提是确保被吸附物体的表面必须平整且光滑，以确保密封性。同时，需要定期清洁和保养吸盘表面，避免污垢和腐蚀，这对其长期维护提出了较高的要求。
\subsubsection{仿生结构}
\label{subsec:label}
在处理外形复杂的物品时，多指灵巧手的仿生设计提供了一种高效的夹持解决方案。这些灵巧手的设计灵感来源于人类手部的结构和运动能力，具备多个关节和能够独立控制的手指，从而能够执行如捏合、旋转和紧握等多样化的抓取动作。这种设计特别适用于那些对灵活性和精确控制有高要求的应用环境。

柔性夹持器则采用柔软材料，如硅胶或弹性聚合物，其设计允许夹持器根据物体的具体形状和尺寸进行自适应调整。这种夹持器能够以温和的方式处理不同形状的物体，适合于易损或不规则物品的搬运。

腱驱动手则模仿人类手臂的腱结构，通过线缆或弹性材料来控制手指的开合动作。这种设计不仅提供了强大的夹持力，还允许手指进行灵活的运动，从而实现更为精细的操作。

不完全驱动手的设计中，手指之间可能会共享一些驱动元件，这种设计策略有助于减少所需的驱动部件数量，从而提高整个系统的可靠性，并在一定程度上降低成本。

最后，生物启发自适应夹持器从动物或昆虫的夹持机制中汲取灵感，例如模仿螯虎或章鱼的吸盘结构，这样的设计能够在应对不同形状和尺寸的物体时，展现出高效的夹持能力和良好的自适应性。

\newpage
\section{循迹研究综述}
\subsection{传统而有效的方法\cite{intro2023robot}}
\label{subsec:label}
\subsubsection{传感器：红外传感器、光敏电阻等}
\label{subsec:label}
在现代机器人技术领域，传感器的多样性和功能性至关重要，其中红外传感器因其独特的传感机制而广泛使用。红外传感器的工作原理基于红外光的发射与接收，它们能够发射特定波长的红外光，并检测由物体表面反射回来的红外光。反射光的强度直接影响传感器的输出电压，这一电压信号随后会被送入电压比较器进行处理。

电压比较器的作用是将接收到的模拟电压信号与一个预设的基准值进行比较，从而产生一个逻辑电平输出。这种逻辑电平信号具有清晰的高低电平界限，易于数字控制器识别和处理，从而实现对传感器信号的快速响应和精确控制。

尽管红外传感器和光敏电阻等在传感能力上可能存在一定的同质性，但红外传感器因其在机器人比赛中的广泛应用，已成为传统传感方法中的一个典型代表。它们在提供距离测量、障碍物检测以及环境光强度评估等方面发挥着重要作用，是实现机器人自主导航和智能交互的关键组件。
\begin{figure}[ht]
  \centering
  
  \caption{ 常见的红外传感器}
\end{figure}

常见的使用方案是在循迹车的前方布置对称的红外传感器。当线出现在红外传感器的正下方，它便会给控制电路采取行动的信号。例如当需要小车保持在黑色边线的赛道内时，如果侧边传感器有信号，则控制向另一个方向转弯。这种实现非常简单直观。

然而红外传感器的缺陷在于其只能给出是否检测到线的信息，而不能给出线的远近、角度信息，这使得它无法实现更加复杂和高效的控制算法。

\subsubsection{算法：从if-else到PID}
\label{subsec:label}
在空间上离散的点观测传感器虽然提供了有限的状态数，但这些状态足以支持基本的控制逻辑。例如，通过简单的条件判断（if-else逻辑），可以实现对小车行为的简单控制。然而，这种方法的局限性在于其缺乏灵活性，固定的控制指令可能无法在所有情况下都实现最优控制。例如，小车可能会在左右摇摆中陷入循环，导致时间和能量的浪费。

为了提高控制的精确度和灵活性，可以使用由多个点观测传感器组成的阵列，如线性CCD传感器。这种传感器阵列可以提供更丰富的信息，允许我们更细致地感知环境。以线性CCD为例，它包含多个光敏电阻，可以连续或离散地测量与特定线条之间的距离。通过将黑线居中于CCD传感器的正中间定义为基准状态，可以量化地表示出偏离这一状态的误差\cite{CCD}。

在循迹算法中引入PID（比例-积分-微分）控制算法，可以显著提高控制性能。PID控制器通过设定一个中间状态作为基准，利用传感器阵列检测到的距离作为误差输入，动态调整小车的轮速差，以保持小车在预定轨迹上的稳定运行。这种方法不仅能够实现更平滑的循迹，还能提高循迹的速度和效率。

具体来说，PID控制器的三个组成部分——比例（P）、积分（I）和微分（D）——共同作用于控制过程。比例部分响应当前误差，积分部分响应误差的累积，而微分部分则响应误差的变化率。通过调整这三个参数，可以优化小车对轨迹的跟踪性能，减少过冲和振荡，实现更稳定和精确的控制。

\subsection{更灵活高效的新方法}
\label{subsec:label}
\subsubsection{计算机视觉\cite{opencv}}
\label{subsec:label}
采用计算机视觉方法可以为系统获得更广的感受野和更复杂的信息。传统的方式是首先获取图像，把图像转化成灰度图再进行二值化，得到黑白图像。黑色点的平均横坐标反映了循迹线的倾斜程度。据此，可以设置阈值或PID使得小车保持循迹。
\begin{figure}[ht]
  \centering
   \begin{subfigure}[b]{0.3\textwidth}
     \centering
     
     \caption{直行}
     \label{fig:label}
   \end{subfigure}
   \hfill
 \begin{subfigure}[b]{0.3\textwidth}
   \centering
   
   \caption{左转}
   \label{fig:label}
 \end{subfigure}
 \hfill
 \begin{subfigure}[b]{0.3\textwidth}
   \centering
   
   \caption{右转}
   \label{fig:label}
 \end{subfigure}
 \hfill
  \caption{经过灰阶化-二值化的图像}
\end{figure}

在嵌入式系统的单片机应用中，矩阵运算的复杂性往往导致处理时间的增加，这直接影响了移动机器人的运行速率。为了解决这一问题，对算法进行优化显得尤为关键。优化的首要步骤是识别并筛选出对决策过程至关重要的信息。具体而言，只有那些与机器人距离较近的物体才应当被纳入考虑范围，而其他无关部分则可以被忽略，从而减少不必要的数据处理。

进一步地，图像序列中的黑色轨迹可以通过间隔采样的方式来提取，而不是对每一帧图像进行详尽的分析。这种方法可以显著降低计算量。

此外，卷积操作是一种有效的技术，它能够减少需要处理的数据量，通过识别图像中的关键特征来简化问题。通过采用池化技术，我们可以将矩阵划分为多个较小的区域，每个区域的大小与卷积核相匹配。在这些区域中，我们可以选择使用区域内元素的最大值或平均值来概括该区域的特征，从而实现对整体特征的高效替代。

\begin{figure}[ht]
  \centering
 \begin{subfigure}[b]{0.4\textwidth}
   \centering
   
   \caption{间隔采样}
   \label{fig:label}
 \end{subfigure}
 \hfill
 \begin{subfigure}[b]{0.4\textwidth}
   \centering
   
   \caption{最大值池化}
   \label{fig:label}
 \end{subfigure}
 \hfill

\end{figure}
\newpage
\subsubsection{强化学习}
\label{subsec:label}
2024年Yu Cao等人进行了深度强化学习循迹机器人的理论研究\cite{cao2024path}。他们将机器人与线路的横向偏差、机器人与路径之间的方向误差、机器人的速度和角速度等信息作为状态，而将机器人速度的变化率作为行动。在奖励函数中纳入与误差成正比的惩罚、与速度成正比的奖励以及惩罚机器人在困难弯道停下的参数。

\begin{figure}[ht]
  \centering
  
  \caption{状态定义物理量\cite{cao2024path}}
\end{figure}

\[ r\left(t\right)=-k_{1}\left|e_{p}\left(t\right)\right|+k_{2}v\left(t\right)\left(1-\frac{1}{e_{tol}}\left|e_{p}\left(t\right)\right|\right)-k_{3}F\left(t\right) \]

在随机生成的环境中进行了50万次交互之后，机器人的路径实现收敛。相比传统的PP控制方法，采用深度强化学习的机器人有了自适应的速度控制能力，可以适应不同曲率的路径，还有相当不错的泛化能力，在随机生成的不同路径中均有优秀的效果。

根据现实硬件情况在Webbot中建模并进行虚拟环境的预训练，再将完成训练的模型下载到实际小车中，就可以实现该方法的实际运用。
\section{避障研究综述}
\label{sec:label}
\subsection{需要获取的信息和相关传感器}
\label{subsec:label}
\subsubsection{障碍物信息}
\label{subsec:label}
\paragraph{红外避障传感器}

红外传感器的工作原理基于一对红外发射器和接收器的配合。发射器发出特定频率的红外光波，当这些光波遇到障碍物时，它们会被反射回来并被接收器捕捉。在传感器的正前方如果存在障碍物，传感器将输出低电平信号；相对地，如果传感器的探测范围内没有障碍物，它将返回高电平信号。

红外传感器的测距机制采用的是三角测量法。这种方法的一个显著特征是，白色物体由于其较高的反射率，能够被检测到更远的距离；而黑色物体由于较低的反射率，其可探测距离相对较短。此外，红外传感器无法有效检测透明物体或接近黑体的物体。物体的面积大小也会影响其可探测距离，面积较大的物体可以被探测到更远的距离，而面积较小的物体则探测距离较短。传感器还能够检测到偏移角度达40°的物体，并且其响应速度通常优于超声波传感器。

值得注意的是，当障碍物距离传感器非常近时，反射回来的红外光波的强度（L值）会显著增加，可能超出电荷耦合器件（CCD）的探测极限。相反，当障碍物距离传感器较远时，L值会减小，这可能导致测量精度下降\cite{jh1}。这些特性对于传感器的应用场景和精度要求具有重要影响。

  \begin{figure}[ht]
    \centering
    
    \caption{红外避障原理 }
  \end{figure}
\newpage
  \paragraph{超声波传感器}
超声波传感器的核心组件包括压电晶体和镍铁铝合金两种材料。利用压电效应，压电晶体构成的传感器能够实现能量的双向转换：将电能转换为机械振动以产生超声波，同时在接收到超声波时，也能将其转换回电能。

超声波具有波长短、频率高、绕射效应小以及方向性好的特点。在传感器的操作过程中，发射器产生机械振动，发射出超声波；当超声波遇到目标物体时，会发生反射或折射，随后由接收器捕获回波并将其转换为电信号进行处理。由于超声波的传播速度是已知的，通过测量发射和接收之间的时间差，可以计算出传感器与物体之间的距离。此外，结合传感器发射器和接收器之间的距离，可以进一步确定障碍物的确切位置。

超声波传感器以其低成本、简单的实现方法和成熟的技术而著称。然而，在进行高精度测量时，必须考虑温度、湿度等环境因素对测量结果的影响。通常，超声波传感器的有效作用距离较短，其探测范围一般在米级，但存在毫米级的探测盲区。由于超声波以锥形波束传播，它能够探测到的是在特定锥形角度范围内最近物体的距离。

超声波传感器的局限性包括较长的测距时间、相对较低的感应精度，以及容易受到其他超声波传感器的干扰，这可能导致测量结果中出现较多的噪声点。
\begin{figure}[ht]
    \centering
    
    \caption{超声波测距原理 }
  \end{figure}

  \paragraph{激光雷达}
  
在润色这段关于激光雷达原理和测量方案的描述时，我会采用更加专业和精确的语言，同时确保文本的流畅性和逻辑性。以下是润色后的段落：

激光雷达的工作原理涉及发射和接收激光束，它可以通过两种主要方式进行测量：一种是利用三角测量原理，类似于红外避障；另一种是利用时间差和速度的测量，类似于超声波。激光雷达系统由发射器和接收器组成，发射器发射激光照射目标物体，而接收器则捕获返回的光波。

机械式激光雷达包含一个装有反射镜的机械结构，通过反射镜的旋转，激光束能够在一个平面上进行扫描，从而获取该平面上各个点的距离信息。

在测量方案方面，主要有两种技术路线：基于飞行时间（Time of Flight, TOF）的测量和三角测距。TOF的基本原理可以用公式 \( d = \frac{ct}{2} \) 表示，其中时间 \( t \) 的测量是整个过程中最关键的部分。时间测量的方法主要有三种：第一种是直接测量法，通过脉冲激光直接测量传播时间，但由于光速极高，这种方法对时间测量设备的精度要求极高，导致成本昂贵；第二种是差频测量法，通过发射调频连续波并测量反射波之间的频率差来确定时间；第三种是相移测量法，传感器以已知频率发射调制光，并测量发射信号与接收信号之间的相位差，从而根据调制波的波长和相位差计算出距离。

三角测距的原理与红外测距相似，此处不再详细描述。

激光雷达在测距方面具有一些显著特点：测量的可靠性与接收信号的幅度平方成反比，具有高角度分辨率和高测距精度。然而，它在测量远距离物体和黑色物体时可能存在困难，透明材料的测量也较为复杂。此外，激光雷达的成本较高，价格昂贵；采用三角测距的激光雷达在量程上通常受到限制，一般不超过几米，并且精度相对较低\cite{jh1}。

  \paragraph{毫米波雷达}
  
毫米波雷达是一种先进的雷达传感器，它利用毫米波段的电磁波来测量距离、相对速度和方向等参数。在车辆行驶过程中，毫米波雷达向前方发射电磁波脉冲。当这些脉冲遇到障碍物时，会反射回来形成回波。通过对这些反射波的频率变化进行分析——即发射频率与接收频率之间的差值——可以检测到前方或对面是否存在障碍物、障碍物的距离、相对速度以及它们的方向。

毫米波雷达的工作原理与前述雷达技术相似，但它具有一些独特的特性。首先，毫米波雷达的检测距离较长，能够覆盖更远的范围。其次，它在金属表面以及夜间、逆光、雾、雨、雪等复杂环境下都能保持良好的性能。然而，对于非金属表面，如人体或纸箱等，由于反射效果不佳，毫米波雷达的检测能力会受到限制。

鉴于毫米波雷达在非金属表面检测上的局限性，以及考虑到实际的具体需求和环境条件，本次设计不将其作为备选方案\cite{jh2}。

  \subsubsection{位置信息}
  \label{subsec:label}
为了实现精确的算法，需要收集必要的位置信息，以确定小车当前所处位置以及小车已完成的路程。位置信息可以用矢量表示，因此需要一个角度信息和一个距离信息，分别由陀螺仪和里程计两种传感器测量并提供。

\subsection{避障算法}
\label{subsec:label}
智能车辆，作为一种具备自主决策能力的自动化机器人，必须能够从其周围环境中获取信息，并基于这些信息做出决策。这使得它们能够执行全局路径规划和在局部危险情况下进行避障，以确保顺利到达目的地并完成既定任务。

全局路径规划为智能车辆提供了在已知地图环境中的最优行驶路线。这种规划确保了车辆能够以最有效的方式从起点导航至终点。与此同时，局部避障算法则赋予了智能车辆对不可预见事件的即时反应能力，这对于处理突发状况和保持车辆安全至关重要。

有效的局部避障算法必须具备快速响应、高实时性和高效率的特点，它们是智能车辆避障功能的核心。这些算法需要能够迅速识别和评估周围环境中的潜在障碍，并计算出避障路径，以避免碰撞并维持车辆的正常运行。

在接下来的讨论中，我们将详细探讨全局规划算法和局部避障算法的设计原理、实现方法以及它们在智能车辆导航中的应用。

\subsubsection{全局规划算法}
\label{subsec:label}
全局规划算法是在全局地图已知（至少是起点和终点已知）的情况下规划出的最优路径，主要目的是节省时间，提高效率。下文总结了目前的部分全局规划算法。
\paragraph{A*算法}
A*算法，首次提出于1968年，是Dijkstra算法与广度优先搜索算法（BFS）的融合之作，其核心在于利用启发式函数 \( f(n) = g(n) + h(n) \) 以加速最优路径的搜索过程。

在该算法中，\( f(n) \) 代表节点的综合优先级函数，其在节点选择过程中起到决定性作用，反映了节点的总成本。\( g(n) \) 表示从起始点到节点n的实际累积成本。而 \( h(n) \) 则是对当前节点至目标点的代价进行预估的估值函数，它基于对地形或环境特征的先验设计，提供了从当前位置n到目的地的最优路径的启发式估算。理想情况下，\( h(n) \) 的值不应超过实际成本，以确保算法能够找到成本最低的路径。

三个函数定义如下：
\begin{enumerate}
\item 	h(n)（启发式函数-代价估值函数）:对于网格点(x,y)，目标点($x_0$,$y_0$)，启发式函数可以如此定义： \( h(n)=\sqrt{(x-x_0)^2+(y-y_0)^2} \) 这个函数值实际上是当前点到重点的欧里几得距离。
\item $g(n)$ (成本函数) :每当从起始点通过路径移动到一个新节点，$g(n)$需要累加上到达该节点的移动成本。设每一步的移动成本是w，则：$g(n_{next})=g(n_{now})+w$
  \item  $f(n)$(总成本):综合上述值，得到$f(n)$评价总成本，最终从中选取节点$f(n)=g(n)+h(n)$

  \end{enumerate}

A*算法以其高效性、灵活性和广泛的适用性而著称，然而，它也存在一些局限性。启发式函数 \( h(n) \) 的选择对A*算法的准确性至关重要，不当的选择可能会导致算法无法找到解或效率降低；算法在运行过程中需要维护开放列表和封闭列表，这将存储大量的节点信息，从而消耗大量的内存资源；在动态变化的环境中，A*算法需要不断地重新计算，这可能会影响到它的实时性能；此外，在处理大型图时，由于需要评估的节点数量庞大，A*算法可能会面临计算量大和速度缓慢的问题。

为了解决这些问题，陈鑫鹏等人提出了一种改进的算法，即等步长分层拓展算法，旨在优化A*算法的性能。该算法通过调整启发式函数和节点扩展策略，以期在保持算法高效性的同时，提高其在特定环境下的适应性和准确性。通过这种方法，可以在一定程度上缓解上述问题，提升A*算法在复杂场景下的应用效果\cite{jh3}。

\paragraph{$D^{*}$算法}
D*算法，亦称为动态A*算法，是在A*算法的基础上发展起来的，最初应用于火星探测器的路径规划。

与A*算法从起点到终点的单向正向搜索不同，D*算法采用的是反向搜索策略，即从终点到起点进行搜索。它利用先前的搜索结果，通过再利用信息实现高效的路径搜索，显著缩减了搜索范围和时间。这种方法特别适用于周围环境未知或存在动态变化的情况。D*算法在初始假设中认为地图上没有障碍，起点到终点的路径为直线，然后在在线运行时不断进行路径的重新规划，以适应全地图未知的路径规划需求。

在D*算法的研究和发展中，秦旭等人对传统D*算法进行了优化。他们改进了子节点的选择策略，并对代价估计函数进行了调整，同时引入了平滑度函数，这些改进使得规划时间减少了20\%。此外，张希闻等人提出了一种扩展Moore型元胞结构的方法，进一步缩短了原D*算法的路径。通过将传统的八点邻接结构扩展到十六点，新算法不仅提高了路径规划的速度，但也相应地增加了空间复杂度。这些改进为D*算法在动态环境中的应用提供了更多的可能性和更高的效率\cite{jh4}。
\newpage
\paragraph{遗传算法}

遗传算法（GA）是John holland 在20世纪70年代初提出的根据生物体进化规律而设计的\cite{jh5}。它是一种全局最优解搜索的启发式优化算法，机制是模拟达尔文进化理论和自然界优胜劣汰。算法流程如下：
\begin{figure}[ht]
  \centering
  
  \caption{遗传算法}
\end{figure}

\paragraph{蚁群算法}

由Marco Dorigo 在1992年提出，是一种用于寻找优化路径的随机搜索算法\cite{jh5}。思路是将城市与城市之间的路径看作一幅图，放置n只蚂蚁在图中移动。每只蚂蚁成功到达终点的路径上会留下信息素，信息素最大的部分就是最优路径
\begin{figure}[ht]
  \centering
  
  \caption{蚁群算法 }
\end{figure}
\newpage
\subsubsection{局部避障算法}
\label{subsec:label}
局部避障算法属于动态规划，主要信息来源是无人车传感器提供的环境信息。此种算法的设计目的是为了让机器人能够灵活调整决策，并尽快对路径上的算法做出响应，根据特点可以分为采样方法、条件约束法和机器学习法。常用的局部路径算法包括人工势场法和虚拟力场法。
\paragraph{人工势场法\cite{jh6}}
人工势场法（Artificial Potential Field, APF）是一种基于虚拟力的路径规划方法，它将车辆在环境中的导航问题转化为在人工构建的势场中寻找路径的问题。在这种方法中，目标点被视为一个引力源，对车辆产生吸引作用，促使车辆向目标方向移动；而障碍物则被视为斥力源，对车辆产生排斥作用，以避免碰撞。车辆的运动是由这两种力的合力所决定的，通过计算合力的方向和大小，车辆能够沿着势场的下降方向移动，从而找到一条既无碰撞又相对最优的路径。

引力势场主要与汽车和目标点之间的距离有关。距离越大，汽车所受的势能值就越大；距离越小，汽车所受的势能值就越小。因此，引力势场的函数是：
$$U_{att}(q)=\frac12\eta\rho^2(q,q_g)$$

其中$\eta$是正比例增益系数，$\rho(q,q_g)$是一个矢量，标识汽车的位置$q$和目标点位置$q_g$之间的欧式距离$|q-q_g|$,矢量方向是从汽车的位置指向目标位置，相应的引力$F_att(q)=-\nabla U_{att}(q)=-\eta\rho(q,q_g)$,是引力场的负梯度，代表引力势场函数$U_att(q)$变化最快的方向。

决定障碍物斥力势场的因素是汽车与障碍物之间的距离。当汽车没有进入障碍物的影响范围时，其受到的势能为 0;汽车进入障碍物影响范围后，汽车受到的势能与距离的关系呈负相关。设车辆当前和目标点的距离为$\rho_g^n$,其中$n$自行定义。具体公式如下：
$$U_{req}(q)=\begin{cases}\dfrac{1}{2}k\left(\dfrac{1}{\rho(q,q_g)}-\dfrac{1}{\rho_0}\right)\rho_g^n,&\quad0\leq\rho(q,q_g)\leq\rho_0,\\\\0\:,&\quad\rho(q,q_g)>\rho_0\end{cases}$$
$F_{req1}$方向为障碍物指向车辆；$F_req2$方向为车辆指向目标点；$F_req$为斥力势场的负梯度作用力。即斥力势场的负梯度作用力等于障碍物指向车辆的斥力和车辆到目标点的斥力之和。
\begin{align}
  \label{}
F_{req}&=F_{req1}+F_{req1}\\
F_req1&=k\left(\frac1{\rho(q,q_g)}-\frac1{\rho_0}\right)\frac{\rho_g^n}{\rho^2(q,q_g)}\\
F_req2&=\frac n2k\left(\frac1{\rho(q,q_g)}-\frac1{\rho_0}\right)^2\rho_g^{n-1}
\end{align}
\begin{figure}[ht]
  \centering
  
  \caption{车辆在改进后势场中的受力}
\end{figure}

根据上述定义的引力场和斥力场函数，可以得到整个空间的复合场，机器人合力势场大小为机器人所受斥力势场和引力势场之和，故合力势场总函数是：
\[ U(q)=U_{att}(q)+U_{req}(q) \]
所受合力是：
\[ F(q)=-\nabla U(q)=F_{att}(q)+F_{req}(q) \]
合力方向决定汽车的行驶朝向；合力大小决定汽车的行驶加速度。
\newpage
应用人工势场法规划出来的路径一般比较平滑安全、算法简明，实时性良好。但是算法也有一些缺点:
\begin{enumerate}
\item 当目标点附近有障碍物时，斥力远远大于引力，车辆将很难到达目的地。
\item 当智能车在某一点引力和斥力刚好大小相等时，车辆会陷入局部最优点。
\item 当车辆到达障碍物附近时，人工势场模型产生的轨迹将出现抖动，不光滑\cite{jh8}。
\item 当引力过大时，即无人车位于起始位置时，无人车可能会忽略障碍物斥力的作用造成碰撞\cite{jh7}。
  \item 传统人工势场只考虑了障碍物与目标点静止不动的静态环境，而车辆实际是在运动的环境中，因此在动态环境下无法取得良好的效果。
\end{enumerate}
针对这些问题，学界产生了很多改进措施。

在研究领域中，王会丽等人通过优化势场函数，有效地解决了局部最优解的问题，成功地识别并定位了全局最优解。李钧泽等人对引力与斥力模型进行了创新性改进，显著提升了算法在避免与原目标端障碍物碰撞以及确保目标可达性方面的性能。此外，他们引入了临时障碍物的概念，进一步优化了解决局部极小值问题的方法。余震中等人则采用了势场强度来替代传统的力矢量，通过在障碍物斥力函数中引入一个系数项，有效地解决了障碍物与目标点距离过近导致的可达性问题。在动态环境下，考虑到移动速度与机器人速度的相互影响，他们引入了速度信息，从而为移动机器人的路径规划提供了一种新的解决方案\cite{jh5}。

\paragraph{模糊逻辑算法}

模糊逻辑算法作为一种广泛应用于在线路径规划的算法，其实施流程通常遵循模型构建和局部路径规划的顺序。该算法的构建并非基于特定对象的数学建模，而是通过观察和记录驾驶员的操作行为，将人类驾驶经验转化为控制指令。在避障路径规划过程中，环境信息经过模糊化处理，并通过模糊规则的连续查询来生成规划结果。部分学者进一步发展了动态模糊环境模型，该模型利用模糊集合来表征环境中运动物体的状态，包括其位置、速度及其方向等属性。随后，通过应用模糊规则对不同方向进行综合评估，以得出最优搜索路径。

模糊算法的优势在于其对车辆的精确定位要求不高，因而展现出较强的鲁棒性，能够适应各种未知环境，并提供有效的路径规划。然而，模糊算法的局限性在于其缺乏自学习能力，一旦模糊规则被设定，便难以根据新的情况进行调整，这限制了算法的灵活性和适应性\cite{jh6}。

\chapter{原型设计方案}

\section{机械设计}
\subsection{车体}
\label{subsec:label}
针对车体的驱动机构设计，我们计划采用一种创新的结构配置，即两个前轮驱动轮结合一个后轮万向轮，形成一种近似倒三角型的车体构型。在车体的纵向布局上，我们采用了双层结构设计，其中下层专门用于安装电机、电池、机械夹爪以及舵机等关键组件。而上层则专门配置了控制硬件和通信硬件，包括但不限于STM32微控制器、电压转换模块、蓝牙通信模块以及超声波传感器等。为了提升OpenMV摄像头的工作效能，我们将其置于一个较高的位置，以扩大其观测范围，从而提高环境感知能力。
\begin{figure}[ht]
  \centering
  
  \caption{车体原型}
\end{figure}
\newpage
\subsection{抓取机构}
在设计抓取机构时，我们必须确保其既能满足摩擦力的要求以稳定夹取物体，同时又要避免过大的尺寸，以防遮挡传感器并干扰其正常运作。经过综合评估机械夹爪、吸盘和仿生结构的优缺点，我们最终选择了一种单自由度的机械夹爪结构。该结构利用电机的旋转驱动齿轮，进而使机械夹爪实现转动，实现一个电机同时控制两侧夹爪的同步运动。夹爪的上下两端各配备一对连杆，用以固定和限位，并通过螺栓和螺母等紧固件进行加固，以确保夹取机构的稳定性和可靠性。

为了防止在抓取货物后，由于颠簸或碰撞导致货物底部与赛道表面摩擦，可能引发的货物滑落或对小车运动的干扰，我们设计了一种机制，使得夹取机构在抓取货物后能够向上翻转，将货物抬升，从而避免这些问题的发生。同时，我们确保抬升后的货物不会对传感器造成干扰，以维持传感器的正常工作状态。
\begin{figure}[ht]
  \centering
  
  \caption{抓取机构概念图 }
\end{figure}
\newpage
\section{测量}
\label{sec:label}
\subsection{小车位姿测量}
\label{subsec:label}
为了对小车进行定位以及进行下一步的计算，我们需要对小车的位姿进行测量。综合考虑各种传感器的性能之后，我们初步决定采用里程计的方式测量小车移动的距离，用陀螺仪测量小车转过的角度，从而确定小车的位姿。
\subsection{循迹中的测量}
\label{subsec:label}
由于我们计划采用视觉循迹方案，所以需要实时图像等视觉数据。我们计划采用OpenMV视觉传感器，其具备计算处理能力，有利于提高图像处理帧率，同时封装性良好，便于我们在短时间内快速学习并应用。
\subsection{避障中的测量}
\label{subsec:label}
我们计划采用激光测距传感器获取距离信息为主，辅以OpenMV视觉传感器进行目标识别。如此可以充分利用OpenMV获得的二维图像信息与较好的前瞻性，并用激光测距测量小车其他方向距障碍物的距离作为补充，并且通过随机算法与人工势场法的加权实现小车前进方向的实时更新，之后会在实现中具体论证可行性。
\section{循迹}
\label{sec:label}

在进行路径追踪方案的选择时，我们经过综合考量，决定采用视觉循迹技术。在文献综述中，我们考察了四种主要的循迹方案：点传感器（包括红外传感器和光敏电阻）、线性CCD、视觉循迹以及强化学习循迹。点传感器方案由于其离散的状态限制，导致控制算法的设计空间受限，且在循迹的平滑性和速度方面未能达到理想的效果。线性CCD虽然可视为点传感器的扩展，但其信息获取的精度和前瞻性仍然有限。

强化学习循迹方案虽然具有较高的灵活性和适应性，但其实现需要复杂的环境感知能力，并且必须在虚拟环境中进行大量的预训练以获得收敛的路径。考虑到实现难度较大，以及我们现有的硬件资源——特别是笔记本电脑显卡的算力限制，我们决定不将其作为首选方案。
\subsection{视觉传感器选择}
\label{subsec:label}
在视觉传感器的选择上，我们决定采用OpenMV作为我们系统的核心组件。OpenMV的显著优势在于其集成了单片机功能，具备强大的计算处理能力，这不仅有助于提升图像处理的帧率，还能显著增强小车的整体性能。此外，OpenMV的配套开发工具具有优良的封装性，其官方文档详尽且易于理解，同时拥有丰富的开放资源。这些特性对于开发者来说，无疑能够大幅度降低学习成本，提高开发效率。
\subsection{算法选择}
\label{subsec:label}
总体上，我们的算法流程首先涉及图像的预处理阶段，随后引入PID控制策略以实现精确的路径跟踪。

我们首先利用OpenMV内置的二值化工具，对裁剪后的图像进行处理，将其转换为黑白图像，以简化后续处理步骤。接下来，我们选择视场中间靠前的区域作为感兴趣区域（Region of Interest, ROI），通过裁剪或矩阵池化技术减小数据矩阵的规模。然后，运用OpenMV自带的拟合函数对黑线进行曲线拟合，从而计算出黑线的方程。根据黑线的斜率，我们确定转向控制量，该控制量的生成将通过PID控制器进行调节，以确保转向过程的稳定性和平滑性。

值得注意的是，PID控制器的误差输入为黑线斜率与预设基准斜率之间的差值，而控制输出则体现为两轮之间的转速差，这直接影响小车的转向行为。
\section{避障算法设计}
\label{sec:label}
\subsection{避障信息获取}
\label{subsec:label}
\subsubsection{位置信息}
\label{subsec:label}
在避障过程中，为了精确确定小车的位置和方向，必须生成其矢量路径。矢量路径包含两个关键信息要素：角度和距离。角度信息的获取依赖于陀螺仪，该设备能够记录小车相对于初始方位的当前方位角度。而距离信息的获取则通过里程计模块实现。

具体而言，我们使用陀螺仪来监测小车当前方位与初始方位之间的夹角变化。当监测到的角度变化在任意一侧超过90度，并且小车行走的距离超过了当前总行程的一定比例时，我们将执行停止前进并原路返回的操作。

对于距离的测量，我们采用里程计模块，具体通过编码器来记录主动轮的转动圈数。随后，利用一系列数学公式将编码器记录的圈数转换为小车在当前方向上实际行走的距离，并进行相应的记录。
\subsubsection{障碍物信息}
\label{subsec:label}
避障需要找到障碍物的位置。我们预计是使用超声波雷达获得与障碍物的距离信息。我们预计采用人工势场法，因此只需要识别前方已有的障碍物并给出当前距离即可收集障碍物信息。
\subsection{避障算法设计}
\label{subsec:label}
避障预期采用人工势场法。依据文献调研结果，结合小车所处的环境状况，预计对人工势场法作出以下改进：
\subsubsection{数学模型改进}
\label{subsec:label}
根据文献调研，人工势场法在使用过程中会出现一些问题，如因障碍物和终点距离太近导致已经到达势能零点、出现局部最优点等。针对这些问题，将数学模型更新如下。

根据梅艺林等人在2024年的工作\cite{jh7}，引力势场的数学模型可以更新成如下形式：
\[ U_{att}(q)=k\frac1{\left(1+e^{\delta\Delta\rho(q,q_g)}\right)^2}+\alpha\Delta\rho(q,q_g) \]

对其求负梯度，改进引力场计算公式：

\[ F_{att}(q)=-\omega\frac{e^{\delta\Delta\rho(q,q_g)}}{\left(1+e^{\delta\Delta\rho(q,q_g)}\right)^2}+\alpha  \]
其中$\omega$引力增益系数,$\delta$是引力变化范围调节因子,$\alpha$是引力上下限调节因子。

改进的斥力势场公式如下：
\[ U_{req}(q)=k\Delta\rho(q,q_g)-k\frac{\ln{(e^{\eta\Delta\rho(q,q_g)}+1)}}{\eta} \]
对其求负梯度，改进斥力场计算公式：
\[ F_{req}(q)=k\frac1{1+e^{\eta\Delta\rho(q,q_g)}} \]
其中k是斥力大小系数,$\eta$是斥力作用范围调节因子,$\Delta\rho(q,q_{g})$是与$\rho(q,q_{g})$相关的调节因子
\subsubsection{思路改进}
\label{subsec:label}
首先，将终点所在直线设定为一级引力场，促使小车不断向最远端行进，以此避免小车可能出现的折返问题；当到达一级引力场时，旋转小车角度与引力场直线方向一致，并向前行进，如果摄像头在地面上识别到终点圆圈，进行放置的步骤；如果摄像头到达墙后仍没有终点圆圈，旋转180度，回到一级引力场，重新向前遍历。

\section{数据通信和回传}
\label{sec:label}
\subsection{蓝牙模块}
\label{subsec:label}
针对我们的场景，考虑到通信距离较短且需要具备一定的抗干扰性能，我们选择了蓝牙模块来实现通信。蓝牙模块以其小巧的体积、易于集成的特性以及低功耗的优势，在板载设计中表现出极高的友好性。特别是蓝牙通信协议中采用的跳频-扩频机制，为我们提供了出色的抗干扰能力。2.4GHz的电磁波能够有效穿透大多数材料的障碍物，确保小车在行驶过程中能够与控制终端保持稳定的信息交换。

在众多蓝牙模块中，我们预计采用HC-05模块。HC-05模块拥有丰富的相关资料和配套的开发工具，使得学习和使用过程变得十分便捷。此外，HC-05模块具备全双工通信能力，能够实现稳定可靠的信息互传。我们将通过电脑或手机向HC-05模块发送指令，并通过该模块控制单片机，同时接收来自传感器的反馈信息。
\begin{figure}[ht]
  \centering
  
  \caption{\label{fig:label} }
\end{figure}
\newpage
\subsection{控制终端}
\label{subsec:label}
为了提高控制和调试的便捷性，我们计划利用蓝牙传输技术将关键数据回传至PC端，以便进行实时观察和控制。通过编码器收集的数据，我们可以准确掌握车轮的累计里程数；而陀螺仪则能够提供小车转动的角度信息。这些数据对于监控小车的运动状态至关重要。

此外，蓝牙模块还允许我们在PC终端对小车进行远程控制，包括但不限于紧急停车和转向操作。这种控制方式在小车遇到问题时尤为有用，因为它使我们能够迅速识别问题所在模块，并进行针对性的调整和调试。这不仅提高了调试的效率，也有助于快速定位并解决问题，确保小车系统的稳定运行和性能优化。
\begin{figure}[ht]
  \centering
  
  \caption{控制终端UI概念图 }
\end{figure}

\section{驱动}
\label{sec:label}
\subsection{处理器}
在硬件选择过程中，我们必须综合考虑设计需求与实际的运算能力。FPGA以其出色的并发处理速度和高可靠性而著称，然而，其调试过程相对复杂。相比之下，传统的硬件解决方案可能会带来更高的技术难度。在这种情况下，采用CPU作为处理单元会相对简便。

对于我们项目中至关重要的图像处理环节，现有的STM32微控制器已经具备了足够的数据处理能力，能够满足算法的需求。鉴于我们团队成员在使用树莓派单片机方面的经验不足，同时考虑到本课程的任务进度要求，我们决定不采用树莓派单片机。相反，我们选择使用OpenMV来处理图像数据，以补充STM32的处理能力。

综上所述，我们初步计划采用以STM32为主控制器、OpenMV为辅助处理器的硬件组合方案，以确保系统的高效运行和快速开发。
\label{subsec:label}
\subsection{电机驱动}
\label{subsec:label}
选择使用PWM方法驱动，并用编码器回传电机数据。选择L298模块同时驱动两轮电机，并使用PID实现电机实际速度的准确、稳定控制。
\subsection{传感器}
\label{subsec:label}
\begin{enumerate}
\item OpenMV:自带单片机，不需要额外的驱动元件。
\item 超声波传感器：可以使用UART串口通信。
\item 里程计：里程计实际上是一个主动轮电机上的编码器，因此不需要进一步的驱动元件。
  \item 陀螺仪：不需要额外的驱动元件，使用$I^{2}C$通信。

  \end{enumerate}
  \newpage
\section{硬件清单}
\label{sec:label}
% Please add the following required packages to your document preamble:
% \usepackage{multirow}
% \usepackage{graphicx}
% \usepackage[table,xcdraw]{xcolor}
% Beamer presentation requires \usepackage{colortbl} instead of \usepackage[table,xcdraw]{xcolor}
% Please add the following required packages to your document preamble:
% \usepackage{multirow}
% \usepackage{graphicx}
% \usepackage[table,xcdraw]{xcolor}
% Beamer presentation requires \usepackage{colortbl} instead of \usepackage[table,xcdraw]{xcolor}
\begin{table}[ht]
\centering
\resizebox{0.5\textwidth}{!}{%
\begin{tabular}{|
>{\columncolor[HTML]{FFFFFF}}c |
>{\columncolor[HTML]{FFFFFF}}c |
>{\columncolor[HTML]{FFFFFF}}c |}
\hline
\textbf{类别}                                   & \textbf{名称/型号}   & \textbf{数量} \\ \hline
处理器                                           & CPU/STM32f407ZGT & 1           \\ \hline
\cellcolor[HTML]{FFFFFF}                      & OpenMV           & 1           \\ \cline{2-3} 
\cellcolor[HTML]{FFFFFF}                      & 超声波雷达           & 3           \\ \cline{2-3} 
\cellcolor[HTML]{FFFFFF}                      & IMU      & 1           \\ \cline{2-3} 
\multirow{-4}{*}{\cellcolor[HTML]{FFFFFF}传感器} & 里程计（用编码器实现）             & 1           \\ \hline
通信                                            & 蓝牙模块/HC-05       & 1           \\ \hline
\cellcolor[HTML]{FFFFFF}                      & 电机 (含直流电机和舵机）           & 3           \\ \cline{2-3} 
\cellcolor[HTML]{FFFFFF}                      & 电机驱动器/L298         & 2           \\ \cline{2-3} 
\multirow{-3}{*}{\cellcolor[HTML]{FFFFFF}动力}  & 电机上编码器              & 3           \\ \hline
\cellcolor[HTML]{FFFFFF}                      & 主动轮              & 2           \\ \cline{2-3} 
\multirow{-2}{*}{\cellcolor[HTML]{FFFFFF}车轮}  & 万向轮              & 1           \\ \hline
\end{tabular}%
}
\caption{}
\label{tab:my-table}
\end{table}
\chapter{人员分工与进度控制}
\section{人员分工}
\label{sec:label}
% Please add the following required packages to your document preamble:
% \usepackage{booktabs}
% \usepackage{graphicx}
% Please add the following required packages to your document preamble:
% \usepackage{booktabs}
% \usepackage{graphicx}
% Please add the following required packages to your document preamble:
% \usepackage{multirow}
% \usepackage{graphicx}
% Please add the following required packages to your document preamble:
% Please add the following required packages to your document preamble:
% \usepackage{multirow}
% \usepackage{graphicx}
\begin{table}[ht]
\centering
\resizebox{0.8\textwidth}{!}{%
\begin{tabular}{|c|c|c|}
\hline
姓名                   & 主要负责内容 & 辅助内容                                                                           \\ \hline
\multirow{2}{*}{邱璟祎} &硬件驱动和通讯   & \multirow{2}{*}{\begin{tabular}[c]{@{}c@{}} 识别算法\\软件\end{tabular}} \\ \cline{2-2}
                     & 循迹算法   &                                                                                \\ \hline
\multirow{3}{*}{周俊豪} & 避障算法   & \multirow{3}{*}{\begin{tabular}[c]{@{}c@{}}硬件驱动\end{tabular}} \\ \cline{2-2}
                     & 车体设计   &                                                                                \\ \cline{2-2}
                     & 运动控制   &                                                                                \\ \hline
\multirow{2}{*}{张峻瑜} & 机械臂设计   & \multirow{2}{*}{\begin{tabular}[c]{@{}c@{}}车体建模\\硬件驱动\end{tabular}} \\ \cline{2-2}
                     & 识别算法和软件   &                                                                                \\ \hline
\end{tabular}%
}
\caption{人员分工表}
\label{tab:my-table}
\end{table}
\newpage
\section{进度控制}
\label{sec:label}
% Please add the following required packages to your document preamble:
% \usepackage{booktabs}
% \usepackage{graphicx}
% Please add the following required packages to your document preamble:
% \usepackage{booktabs}
% \usepackage{graphicx}
% Please add the following required packages to your document preamble:
% \usepackage{booktabs}
% \usepackage{graphicx}
% Please add the following required packages to your document preamble:
% \usepackage{booktabs}
% \usepackage{graphicx}
\begin{table}[ht]
\centering
\resizebox{\textwidth}{!}{%
\begin{tabular}{@{}cc@{}}
\toprule
时间节点        & 阶段任务                        \\ \midrule
7月9日-7月11日  & 进一步完善详细设计方案，采购零件，编写部分硬件单元代码 \\
7月11日-7月15日 & 加工零部件，组装小车硬件，编写部分硬件单元代码     \\
7月15日-7月17日 & 单元控制代码编写，完成硬件测试             \\
7月17日-7月22日 & 完成单元控制代码编写和单元测试             \\
7月22日-7月24日 & 软件集成，硬件通讯部分代码编写与调试          \\
7月24日-7月25日 & 自动抓取货物与放置货物集成调试与细节优化        \\
7月26日-7月27日 & 循迹模式小车运动集成调试与细节优化           \\
7月27日-7月28日 & 避障模式小车运动集成调试与细节优化           \\
7月28日-7月29日 & 小车整体最终调试，准备比赛               \\ \bottomrule
\end{tabular}%
}
\caption{进度控制表}
\label{tab:my-table}
\end{table}
\bibliographystyle{IEEEtran}
\bibliography{references}

\end{document}

%%% Local Variables:
%%% mode: LaTeX
%%% TeX-master: t
%%% End:

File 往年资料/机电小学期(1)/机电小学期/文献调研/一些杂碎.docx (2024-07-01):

运动方式

轮式：

轮式移动的AGV小车可以分为三种：两轮差速移动AGV小车、带带舵轮的四轮移动AGV小车和三轮移动AGV小车。两轮差速移动AGV小车具有节省空间、机动性好等特点，被广泛应用在各大企业的生产工厂内。三轮移动和四轮移动的AGV小车则能够以轮式移动为特征的AGV小车，和步行、爬行或是其他非轮式的移动机器人相比，更加快捷，工作效率也更高。另外还具有无人值守自动化搬运、承载重量大、结构简单、可控性强、安全性好等优点。与物料送中常用的堆垛机、单轨小车、传送带、传送链，AGV的活动区域不受场地、道路和空间的限制。因此，在自动化物流系统中，最能充分地体现其自动性和柔性，实现高效、经济、灵活的无人化生产。

对于四轮式AGV小车，又可以细分为前驱、后驱以及四驱。前驱或者后驱由于驱动电机数量少，能够增加内部空间，在空间的利用上有更多的余地，减轻小车重量，耗能低。但是由于前后配重不均匀，另一侧的车轮在行进过程中容易失去抓地力，出现转向不足或者转向过度的问题，对于操控性有负面影响。四驱的AGV小车则前后配重相对均匀，同时由于四轮均能够获得动力，行进过程操控性更好，容错性更高，更为稳定，在路面状况较为复杂时也拥有更好的适应能力，但是会导致小车自重较大，行动的灵活性受到影响，耗能也更大。


图1 轮式小车

步行式：

步行式机器人分为单腿式、双腿式和多腿式等等类别。

首先，足式机器人的运动轨迹是一系列离散的足印,轮式和履带式机器人的则是 条条连续的辙迹。崎岖地形中往往含有岩石、泥土、沙子甚至峭壁和陡坡等障码物可以稳定支撑机器人的连续路径十分有限,这意味着轮式和履带式机器人在这种地形中已经不适用,而足式机器人运动时只要离散的点接触地面,对这种地形的适应性较强,正因为如此,足式机器人对环境的破坏程度也较小。

第二,足式机器人的腿部具有多个自由度,使运动的灵活性大大增强。它可以通 过调节腿的长度保持身体水平,也可以通过调节腿的伸展程度调整重心的位置,因此不易翻倒,稳定性更高。同时，机器人的身体可以平稳地运动而不必考虑地面的粗糙程度和腿的放置位置。当机器人需要携带科学仪器和工具工作时,首先将腿部固定,然后精确控制身体在三维空间中的运动, 就可以达到对对象进行操作的目的。


图2 步行式机器人

履带式：

履带车对地面单位压力小，下陷小，附着能力强，行驶通过能力强。一般按行驶系结构可分为前桥（从动桥）装雪橇或车轮、后桥装履带的半履带式，前后桥都装履带的全履带式和可互换使用车轮、履带的车轮-履带式三种类型。

履带能够使受力面积加大，增大摩擦，抓地力变好，相对地面的压强减小，不容易造成陷轮。并且结构简单，结实耐用。而且履带板上有花纹，并能安装履刺，所以在雨、雪、冰或上坡等路面上能牢牢地抓住地面，不会滑转。履带适合在条件不好的环境下作业。例如雪地、山坡、草地等。但是在生产成本上，履带车要比轮式车高很多。


图3 履带式小车

转向方式

麦克纳姆轮：

随着现代控制技术和计算机技术的发展，移动机器人在越来越多的领域开始发挥至关重要的作用，作为移动机器人的关键部件，移动平台可以保证机器人的移动性和稳定性，成为了机器人领域的研究重点。其中麦克纳姆轮移动平台因具有平面上3个自由度的移动能力而逐渐受到了更多的关注。然而麦克纳姆轮移动平台的轮子并不能够直接转向，它是依靠4个轮子各自不同转速的相互配合来实现全向移动，因此每一个轮子的运动都对整体的运动方向和速度大小有着很大的贡献。

全向轮又被称作麦克纳姆轮，其具体结构设计如图1。可以看出它与普通轮之间的主要区别就在于它的圆周上分布有若干数量的辊子，这些辊子的轴线与轮子的轴线呈一定的夹角（本文所采用的麦克纳姆轮的偏置角为 45°），辊子的外廓线所形成的包络面和轮的原始圆周面重合，这样保证了辊子能与地面一直保持接触[2]。这些辊子还可以自由转动，这使得轮子只受到地面对辊子轴向上的力，而地面对辊子的圆周力则变为了滚动摩擦可以近似看为零。因此，轮子与地面的接触力不再是沿轮子的圆周方向，而是与它呈一定的夹角，所以这种轮子可以在一个方向上受到摩擦力的驱动，而另一个方向上却能够自由移动。由 4 个这样的轮子便可以组合出不同的受力情况，从而使移动平台可以实现平面上3 个自由度的移动。通过对于单轮的运动学分析可以求得全向轮运动的雅各比矩阵，通过控制四个轮的转速来控制运动平台的平动与转动速度。

图中R 表示全向轮轴心到轮外廓圆周面的距离即轮的半径；Vix为第i轮沿X轴方向的分速度；Viy为第i轮沿Y轴方向上的分速度，Vs为辊子的速度；辊子轴线与全向轮轴线夹角为α；ωi为全向轮绕轮轴的转速。i=1、2、3、4，分别代表了左前轮、右前轮、左后轮、右后轮。联立可得矩阵方程：

V_i =(R/4)[1, 1, 1tanα, -tanα, -tanα-1/(l_0), 1/(l_0), -1/(l_0) 1tanα1/(l_0)][ω_1 ω_2 ω_3 ω_4 ]

式中： l_0 =W+Lcosα ，其中 W 为移动平台宽度，L 为其前后轮轴距；而α取 45°，其正负号已被提出，不再区分正负。其逆运动学方程为：

[ω_1 ω_2 ω_3 ω_4 ]=K[V_y V_x ω]=(1/R)[1, cotα, -l_0 1, -cotα, l_0 11, -cotαcotα, -l_0 l_0 ][V_y V_x ω]

普通轮（差速法）：


参考阿克曼（Ackerman）转向几何学原理，即在汽车转向时4个轮胎都近似围绕一个中心点旋转以保证汽车的行驶稳定性。把汽车的形心作为质心，并且忽略路面情况变化等的影响，可得出四轮驱动差速转向小车的运动学模型如图 3所示。


α1 和 α2 分别为前左轮和后左轮，前右轮和后右轮的转角；2L 为左右轮距离；2K 为前后轮轴距；v和 ω 分别为车子质心的线速度和角速度，V1 ，V2 ，V3 ，V4分别为各个轮中心的实际运动方向。由此可以求出各速度和转角的关系。


机械臂的末端执行器

机械手爪：

机械手爪通常采用气动、液动、电动和电磁来驱动手指的开合。气动手爪应用广泛，气 动手爪结构简单、成本低，容易维修，开合迅速，重量轻。但空气介质的可压缩性使爪钳位 置控制比较复杂，稳定性不足，可靠性存疑。液压驱动手爪成本较高。电动手爪的手指开合电动机控制与机器人控制 可以共用一个系统，但是夹紧力比气动手爪、液压手爪小。电磁手爪控制信号简单，但是电 磁夹紧力与爪钳行程有关，只用在开合距离小的场合。液压手爪抓取力大、提升过程可靠、控制精准、动作灵敏，但由于夹紧力大，对于被夹物品的材料刚性有一定的要求。


图4 机械手爪

磁力/真空吸盘：

磁力吸盘有电磁吸盘和永磁吸盘两种。磁力吸盘的特点：体积小，自重轻，吸持力强， 可在水里使用。磁力吸盘广泛应用于钢铁、机械加工、模具、仓库等搬运吊装过程中对块状、 圆柱形导磁性钢铁材料工件的连接，可大大提高工件装卸、搬运的效率，是工厂、码头、仓 库、交通运输等行业最理想的吊装工具。但是对所抓取的物品有磁性的要求。

真空吸盘原理简单，操作相对容易，但是前提是要保证所抓取物品表面足够平整光滑，此外还需要注意对于吸盘盘面的清洁与保护，防止污渍与腐蚀等等，对于后期维护保养的要求较高。


图5 磁力吸盘

仿生多指灵巧手：

简单的夹钳式取料手不能适应物体外形的变化，不能使物体表面承受比较均匀的夹持力， 因此，无法满足对复杂形状、不同材质的物体实施夹持和操作。为了提高机器人手爪和手腕 的操作能力、灵活性和快速反应能力，使机器人能像人手一样进行各种复杂的作业，如装配 作业、维修作业、设备操作以及机器人模特的礼仪手势等，就必须有一个运动灵活、动作多 样的灵巧手。

多关节柔性手能针对不同外形物体实施抓取，并使物体表面受力比较均匀，每个子指由多个关节串接而成。手指传动部分由牵引钢丝绳及摩擦滚轮组成。每个指由2根钢丝绳牵引，一侧为握紧，另一侧为放松。驱动源可采用电机驱动或液压、气动元件驱动。柔性手腕可抓取凹凸外形物体并使其受力较为均匀。柔性材料做成的柔性手一端固定，一端为自由的双管合一的柔性管状子爪。当一侧管内充入气体（液体），另一侧管抽出气体（液体）时，形成压力差，柔性手爪就向抽空侧弯曲。此种柔性手适用于抓取轻型、圆形物体，如玻璃器皿等。


图6 仿生多指灵巧手

参考文献：

[1] 张忠民、郑仁辉：《基于模糊PID的麦克纳姆轮移动平台的控制算法》，《应用科技》，2017年第06期。

[2] 高至、李传昌、梁世伟、兰晔、李岳洪：《智能车路径识别及转向控制的研究与实现》，《南方农机》，2019年第12期。

[3] 赵艳娥、张建武：《轮毂电机驱动电动汽车电子差速系统研究》，《系统仿真学报》，2008年总第18期。

[4] 杨俊驹、林睿、王振华、孙立宁：《轮式移动机器人运动控制系统研究与设计》，《现代电子技术》，2016年第02期。

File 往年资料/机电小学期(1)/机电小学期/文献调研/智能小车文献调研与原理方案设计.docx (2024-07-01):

智能小车文献调研与原理方案设计

荆尹浩宇 滕一铭 张佳悦

2021年7月2日

目录

# 智能小车文献调研与原理方案设计

# 1. 引言

为完成《机电系统设计实践》课程的主要任务，将智能小车更好地予以实现，笔者将通过需求分析、任务分解、文献综述初步明确智能小车的要求及相应的需要细化的问题，了解目前的相关技术进展，并据此进行初步的原理方案设计。

智能小车是计算机、传感、通信、人工智能、自动控制等技术的集合，将环境感知、自动决策、自动驾驶等功能融为一体，是典型的现代高新技术结合体。近年来，智能小车在应用和技术上都取得了很大的进步，它也因可以搭载多种模块且具有强大的环境适应能力，被广泛地应用于各领域。

本文中所实现的智能小车指能够自主移动并实现在循迹场景与避障场景中自主完成抓取、运输和卸载货物工作的AGV轮式小车。在对智能小车任务进行需求分析与任务分解后，本文将从机械结构及运动控制、循迹传感器及算法、避障传感器及算法、控制器硬件、数据通讯、电机与驱动六部分进行文献调研并综述。之后，本文将通过需求分析与文献调研所得结果，进行初步原理方案的设计。

# 2. 需求分析与任务分解

课程的总体任务为“设计并实现一个机电系统，在2种不同场地，分别按规定路线自助寻线与无固定路线自助避障，将给定货物从一个指定位置运输到另一指定位置”，可将此任务分解为车架主体、抓取结构、任务所用传感器、控制器硬件、数据通讯、电机与驱动、总电源与二次电源七个方面进行逐个分析。

## 2.1 车架主体

车架整体尺寸：在自助避障任务中，障碍物间的间距不小于350mm，因此，小车的宽度应小于350mm并留出适量裕度。

车架选用材料：车架材料的选择需具有一定刚度以保证结构稳定性，同时也应注意适当减重，使小车尽量轻便以提高速度。

车架空间结构：由于小车的占地面积不能过大，且需要在车架上装配多种元器件和电子线路，可以考虑将小车做成二层或三层结构。在设计车架空间结构时，需要考虑车轮、车体、模块电路板及电机等的重力配平，以提高稳定性。

驱动与转弯方式：驱动方式上，可以选择使用两轮或三轮并采用两轮驱动，也可以选择使用四轮并采用四轮驱动或者后轮驱动，几种方式各有优劣，将在后文中进行分析比较。转弯方式上，可以采用普通轮并通过差速转向或者偏转前轮转向予以实现，也可以采用麦克纳姆轮通过4个轮子不同转速的相互配合来实现全向移动，其特点及优劣比较也将在后文中予以阐述。

## 2.2 抓取结构

机械爪及舵机：货物尺寸为直径30mm，高40mm，其重量为50g，因此抓取结构中的机械爪需与货物尺寸相匹配，且相应舵机需要有足够的力矩。

抓取结构大小与工作空间：因小车本身体积有限，因此抓取结构不应过大。除此之外，还需考虑抓取结构的工作空间，如不能遮挡摄像头视野等。

抓取结构性能：一方面，抓取结构应尽可能精简小巧，以此保证较小影响车架结构并提高抓取稳定性；另一方面，需要从设计机构的角度提升抓取稳定性，确保将货物装上小车。

## 2.3 任务所用传感器

任务所用传感器可能有红外传感器、超声传感器、线阵CCD传感器、OpenMV等，不同传感器的作用不同，将在下文进行具体介绍与分析。在考虑传感器作用及选择之外，还需考虑传感器器件如何在车架上进行装配，从而合理安排车体结构。

## 2.4 控制器硬件

常用的控制器包括STM32F407开发板、MSP430F149开发板、Cyclone IV FPGA开发板等，不同控制器的性能不同，可以从接口需求、计算能力、传感功能需求、可利用资源、可实现性等方面综合考量进行选择。

## 2.5 数据通讯

需要实现的通讯任务主要包括实时图像、指令数据、状态参数和舵机命令的传输，具体的通讯方式包括USB线、异步串口、CAN和以太网等有线通讯方式和蓝牙、Zigbee、WiFi等无线通讯方式。不同的通讯方式有其各自的特点及优缺点，具体选型需要依据传输数据量、数据传输延时、具体元器件特点、车载与PC端软件开发量、硬件接口等因素综合决策。

## 2.6 电机与驱动

可以选用的电机有多种类型，具体包括航模舵机、直流电机、永磁同步电机、音圈电机、步进电机、交流异步电机等，其中前两种电机在智能小车中应用较多，不同电机之间的性能比较将在后文予以介绍。

## 2.7 总电源与二次电源

由于单片机、电机、舵机等不同元器件的所需电压不同，需要进行相应的电源与二次电源的选择，具体选择将在原理方案设计部分予以确定。

# 3. 文献综述

## 3.1 机械结构及运动控制

### 3.1.1 运动方式

现有的可以运动方式主要有三种，即轮式、步行式与履带式，下文将分别综述二者的实现方式及特点。

      3.1.1.1 轮式运动

轮式移动的AGV小车可以分为三种：两轮差速移动AGV小车、带舵轮的四轮移动AGV小车和三轮移动AGV小车。两轮差速移动AGV小车具有节省空间、机动性好等特点，被广泛应用在各大企业的生产工厂内。三轮移动和四轮移动的AGV小车则能够以轮式移动为特征，与步行、爬行或是其他非轮式的移动机器人相比，更加快捷，工作效率也更高，同时还具有无人值守自动化搬运、承载重量大、结构简单、可控性强、安全性好等优点。与物料送中常用的堆垛机、单轨小车、传送带、传送链相比，AGV的活动区域不受场地、道路和空间的限制。因此，在自动化物流系统中，最能充分地体现其自动性和柔性，实现高效、经济、灵活的无人化生产。

对于四轮式AGV小车，又可以细分为前驱、后驱以及四驱。前驱或者后驱由于驱动电机数量少，能够增加内部空间，在空间的利用上有更多的余地，减轻小车重量，耗能低。但由于前后配重不均匀，另一侧的车轮在行进过程中容易失去抓地力，出现转向不足或者转向过度的问题，对于操控性有负面影响。四驱的AGV小车则前后配重相对均匀，同时由于四轮均能够获得动力，行进过程操控性更好，容错性更高，更为稳定，在路面状况较为复杂时也拥有更好的适应能力，但是会导致小车自重较大，行动的灵活性受到影响，耗能也更大。


图1 轮式小车

      3.1.1.2 步行式运动

步行式机器人分为单腿式、双腿式和多腿式等等类别。

首先，足式机器人的运动轨迹是一系列离散的足印，轮式和履带式机器人的则是一条条连续的辙迹。崎岖地形中往往含有岩石、泥土、沙子甚至峭壁和陡坡等障碍物，可以稳定支撑机器人的连续路径十分有限，这意味着轮式和履带式机器人在这种地形中已经不适用。而足式机器人运动时只需要离散的点接触地面，对这种地形的适应性较强。正因为如此，足式机器人对环境的破坏程度也较小。

第二，足式机器人的腿部具有多个自由度,使运动的灵活性大大增强。它可以通过调节腿的长度保持身体水平,也可以通过调节腿的伸展程度调整重心的位置，因此不易翻倒，稳定性更高。同时，机器人的身体可以平稳地运动而不必考虑地面的粗糙程度和腿的放置位置。当机器人需要携带科学仪器和工具工作时，可以通过首先将腿部固定，之后精确控制身体在三维空间运动的方式，达到对对象进行操作的目的。


图2 步行式机器人

      3.1.1.3 履带式运动

履带车对地面单位压力小，下陷小，附着能力强，行驶通过能力强。一般按行驶系结构可分为前桥（从动桥）装雪橇或车轮、后桥装履带的半履带式，前后桥都装履带的全履带式和可互换使用车轮、履带的车轮-履带式三种类型。

履带能够使受力面积加大，增大摩擦，抓地力变好，相对地面的压强减小，不容易造成陷轮，并且结构简单，结实耐用。而且履带板上有花纹，可以安装履刺，所以在雨、雪、冰或上坡等情况时能牢牢地抓住地面，不会滑转。履带适合在条件不好的环境下作业，例如雪地、山坡、草地等。但是在生产成本上，履带车要比轮式车高很多。


图3 履带式小车

### 3.1.2 转向方式

在目前设计的智能小车中，转向多采用普通轮并使用差速法实现，也可以通过全向轮（即麦克纳姆轮）实现。

      3.1.2.1 普通轮（差速法）

参考阿克曼（Ackerman）转向几何学原理，即在汽车转向时4个轮胎都近似围绕一个中心点旋转以保证汽车的行驶稳定性。把汽车的形心作为质心，并且忽略路面情况变化等的影响，可得出四轮驱动差速转向小车的运动学模型如下图所示。


图4 四轮驱动差速转向小车的运动学模型

α1和α2分别为前左轮和后左轮，前右轮和后右轮的转角；2L为左右轮距离；2K为前后轮轴距；v和ω分别为车子质心的线速度和角速度；V1，V2，V3，V4分别为各个轮中心的实际运动方向。由此可以求出各速度和转角的关系。


      3.1.2.2 麦克纳姆轮

随着现代控制技术和计算机技术的发展，移动机器人在越来越多的领域开始发挥至关重要的作用。作为移动机器人的关键部件，移动平台可以保证机器人的移动性和稳定性，成为了机器人领域的研究重点。其中麦克纳姆轮移动平台因具有平面上3个自由度的移动能力而逐渐受到了更多的关注。然而麦克纳姆轮移动平台的轮子并不能够直接转向，它依靠4个轮子各自不同转速的相互配合来实现全向移动，因此每一个轮子的运动都对整体的运动方向和速度大小有着很大的贡献。

全向轮又被称作麦克纳姆轮，它与普通轮之间的主要区别就在于它的圆周上分布有若干数量的辊子，这些辊子的轴线与轮子的轴线呈一定的夹角（本文所采用的麦克纳姆轮的偏置角为45°），辊子的外廓线所形成的包络面和轮的原始圆周面重合，这样保证了辊子能与地面一直保持接触。这些辊子还可以自由转动，这使得轮子只受到地面对辊子轴向上的力，而地面对辊子的圆周力则变为了滚动摩擦，可以近似看为零。因此，轮子与地面的接触力不再是沿轮子的圆周方向，而是与它呈一定的夹角，所以这种轮子可以在一个方向上受到摩擦力的驱动，而在另一个方向上自由移动。由4个这样的轮子便可以组合出不同的受力情况，从而使移动平台可以实现平面上3个自由度的移动。通过对于单轮的运动学分析可以求得全向轮运动的雅各比矩阵，通过控制四个轮的转速来控制运动平台的平动与转动速度。

用R表示全向轮轴心到轮外廓圆周面的距离即轮的半径；Vi表示第i轮的速度；α表示辊子轴线与全向轮轴线夹角；ωi表示全向轮绕轮轴的转速；i=1、2、3、4，分别代表左前轮、右前轮、左后轮、右后轮。联立可得矩阵方程：

V_i =(R/4)[1, 1, 1tanα, -tanα, -tanα-1/(l_0), 1/(l_0), -1/(l_0) 1tanα1/(l_0)][ω_1 ω_2 ω_3 ω_4 ]

式中 l_0 =W+Lcosα ，其中W为移动平台宽度，L为其前后轮轴距；而α取45°，其正负号已被提出，不再区分正负。逆运动学方程为：

[ω_1 ω_2 ω_3 ω_4 ]=K[V_y V_x ω]=(1/R)[1, cotα, -l_0 1, -cotα, l_0 11, -cotαcotα, -l_0 l_0 ][V_y V_x ω]

### 3.1.3 机械臂末端执行器

机械臂的末端执行器可以采用机械手爪、磁力/真空吸盘、仿生多指灵巧手等结构，其原理及特点如下。

3.1.3.1 机械手爪

机械手爪通常采用气动、液动、电动和电磁来驱动手指的开合。气动手爪应用广泛，气 动手爪结构简单、成本低，容易维修，开合迅速，重量轻。但空气介质的可压缩性使爪钳位 置控制比较复杂，稳定性不足，可靠性存疑。液压驱动手爪成本较高。电动手爪的手指开合电动机控制与机器人控制可以共用一个系统，但是夹紧力比气动手爪、液压手爪小。电磁手爪控制信号简单，但是电磁夹紧力与爪钳行程有关，只用在开合距离小的场合。液压手爪抓取力大、提升过程可靠、控制精准、动作灵敏，但由于夹紧力大，对于被夹物品的材料刚性有一定的要求。


图5 机械手爪

3.1.3.2 磁力/真空吸盘

磁力吸盘有电磁吸盘和永磁吸盘两种。磁力吸盘的特点：体积小，自重轻，吸持力强， 可在水里使用。磁力吸盘广泛应用于钢铁、机械加工、模具、仓库等搬运吊装过程中对块状、 圆柱形导磁性钢铁材料工件的连接，可大大提高工件装卸、搬运的效率，是工厂、码头、仓 库、交通运输等行业最理想的吊装工具，但是对所抓取的物品有磁性的要求。

真空吸盘原理简单，操作相对容易，但前提是要保证所抓取物品表面足够平整光滑，此外还需要注意对于吸盘盘面的清洁与保护，防止污渍与腐蚀等等，对于后期维护保养的要求较高。


图6 磁力吸盘

3.1.3.3仿生多指灵巧手

简单的夹钳式取料手不能适应物体外形的变化，不能使物体表面承受比较均匀的夹持力，因此，无法满足对复杂形状、不同材质的物体实施夹持和操作。为了提高机器人手爪和手腕的操作能力、灵活性和快速反应能力，使机器人能像人手一样进行各种复杂的作业，如装配作业、维修作业、设备操作以及机器人模特的礼仪手势等，就必须有一个运动灵活、动作多样的灵巧手。

多关节柔性手能针对不同外形物体实施抓取，并使物体表面受力比较均匀，每个子指由多个关节串接而成。手指传动部分由牵引钢丝绳及摩擦滚轮组成，每个指由2根钢丝绳牵引，一侧为握紧，另一侧为放松。驱动源可采用电机驱动或液压、气动元件驱动。柔性手腕可抓取凹凸外形物体并使其受力较为均匀。柔性材料做成的柔性手一端固定，一端为自由的双管合一的柔性管状子爪。当一侧管内充入气体（液体），另一侧管抽出气体（液体）时，形成压力差，柔性手爪就向抽空侧弯曲。此种柔性手适用于抓取轻型、圆形物体，如玻璃器皿等。


图7 仿生多指灵巧手

## 3.2 循迹传感器及算法

### 3.2.1 红外传感器

红外发射管竖直发射出红外线，红外接收管接收反射的红外线，用光电传感器或灰度传感器可以将接收到的红外线光信号转化成电信号。若红外射线照在白色地面上，红外传感器接收到反射回的红外线比较强，转化的电信号也比较强；若红外线照在黑色引导线上，这时反射回的红外线的强度较弱，转化为的电信号也较弱。小车的循迹通过红外传感器接收到的信号强弱来控制，通过转化为的电信号强弱差异，就可以判断并调整小车的行驶路线。

查看源图像

图8 红外传感器（左） 五路红外循迹模块（右）

以五路红外循迹模块为例，其控制算法如下表所示：

表1 五路红外循迹模块控制算法示例表


控制流程大致如下：


图9 五路红外循迹控制流程

红外传感器具有灵敏度高、体积小、易于安装等优点，但由于在循迹模块中其数量通常较少，因此该方法对道路的前瞻性不强，循迹效率不高。

### 3.2.2 线阵CCD

图像信息采集时，单片机的端口与CCD的图像灰度信息输出引脚相连，线阵CCD是单行采集图像的，并且采集回来的数据是灰度值，对灰度值进行二值化和滤波处理后，最终可以确定跑道的路况。

滤波处理多采用时域滤波法，可以采取平均值滤波、中值滤波、限值滤波与滑动平均值滤波等算法，以对数据进行降噪处理。考虑到CCD图像的畸变视角的变化以及环境的影响，阈值的确定通常采用动态阈值法，可以通过取平均电压值、max与min的均值、大津算法等方法求得阈值。此外, 针对每行中的孤立噪点, 可以采用计数法排除。

在对图像进行上述处理后，可以通过跟踪引线的黑线提取算法来提取轨迹线。如果连续黑点数小于某个阈值时, 认为是噪声影响, 而非实际的黑线, 从而可以减少误判概率. 在完成轨迹线的提取后，通过计算可以得出当前小车的方向与黑色引导线之间的位置偏差，接着将此位置偏差信号输入到闭环位置控制系统，经过PID闭环位置控制算法进行调节，将调节后的信号再输入到驱动控制模块，实现对电机在速度上的控制，使小车沿黑色引导线行进。

线阵CCD的优点是路径分辨率高，前瞻性较强，可以更远更早地感知路径的变化，在小车本体跑偏之前修正行进方向，并且可以实时地监控路径的位置，及时纠偏。但此方法的图像获取时间较长，测量效率较低，并且图像精度可能会受扫描运动精度的影响。

### 3.2.3 摄像头

由于摄像头提供的图像信息较多、较复杂，因此在对图像信息进行处理时，首先要对图像进行有效部分提取, 提取出感兴趣区域后，对图像从左到右、从上到下进行隔行扫描，并读取扫描的每个像素点的灰度值，以此为依据进行分割从而提取出循迹小车所在的赛道信息。分割阈值的选择一般也采取动态阈值法，可以从最低灰度等级向高灰度等级进行遍历， 找到第一个灰度等级对应的像素概率为零的灰度级作为最后阈值。在获得赛道信息后，可以根据小车的具体偏移量利用PD控制算法来计算舵机的转角，再利用PID算法闭环调节小车的速度。

由于摄像头与地面之间存在俯角，导致采集到的图像并不是一个方形区域，而是一个近处区域小、远处区域大的梯形区域，图像会出现失真。


图10 梯形失真示意图

对于纵向畸变的矫正，通常采用非均匀行采集的算法，其坐标变换表达式为y=vd。其中d表示两行采样之间的间隔。对于横向畸变，矫正后坐标系之间的变换公式为

x=(CD)/(N-1)(u-N/2) ，式中CD表示视角的底部宽度，N表示总列数。


图11 非均匀行采样示意图

对于赛道曲率的计算有多种算法，最简单的一种方法是利用 q=|(x_3 -x_2 )-(x_2 -x_1 )| 来计算，式中 x_1 、 x_2 和 x_3 为3个实际距离相等的行的黑线位置。赛道曲率还可以用两点法和三点法计算，三点法计算的本质是求三角形的外接圆半径，但往往需要对图像的畸变进行矫正；对于两点法，如果智能车在赛道中心线上，则有 k=(2l_(BC))/(l_(AB)^2 +l_(BC)^2) ；如果小车不在赛道中心线上，则有

其中， A_1 为智能车的左偏移点, 偏距为 l_(AA1) , 曲率为 k_1 ； A_2 为智能车的右偏移点，偏距为 l_(AA2) , 曲率为 k_R 。


图12 小车在赛道中心线上（左） 小车不在赛道中心线上（右）

采用摄像头循迹可以获得二维的图像信息，在前瞻性和纠偏能力上比线阵CCD更优，不过由于其像元数总数多，但每行的像元数比线阵少，因此其图像分辨率比线阵CCD要低，不适用于要求视场大、图像分辨率高的情形。

## 3.3 避障传感器及算法

### 3.3.1 常见避障传感器

3.3.1.1 红外避障传感器

原理：红外避障主要是以红外测距传感器为主，红外测距都是采用三角测距的原理。红外发射器按照一定角度发射红外光束，遇到物体之后，光会反向回来。检测到反射光之后，通过结构上的几何三角关系，就可以计算出物体距离D。

适用范围：可通过电位器旋钮调节探测距离，有效距离范围0~20cm，顺时针调电位器，检测距离增加，逆时针调电位器，检测距离减少。红外避障传感器广泛应用于及机器人避障、避障小车、流水线计数及黑白线寻迹等众多场合。

优势：结构简明，便于装配，成本低廉，反应灵敏，便于近距离路面情况的检测，抗干扰能力强，不会因为周围环境的差别而产生不同的结果。

劣势：只能对路面情况做简单的黑白判别，检测距离和精度有限，传感器高度位置的差异可能会对其检测造成干扰。

3.3.1.2 超声波避障传感器

原理：超声波测距的原理比红外线更加简单，因为声波遇到障碍物会反射，而声波的速度已知，所以只需要知道发射到接收的时间差，即可轻松计算出测量距离，再结合发射器和接收器的距离，就能算出车体到障碍物的实际距离。

适用范围：作用距离一般在5-10m之间，但是会存在一个最小探测盲区，一般在几十毫米。由于需要主动发射声波，因此太远的障碍物会使精度随着声波的衰减而降低，不适合用超声波避障传感器。此外，对于海绵等吸收声波的物体或者在大风干扰的情况下，超声波将无法工作。超声波避障传感器是移动机器人、AGV、无人机、汽车避障中常用的传感器。

优势：结构简单，制造方便，成本较低；超声波对雨、雪、的穿透力强，可以在恶劣天气下工作；超声波对光照和色彩不敏感，可以用于识别透明以及反射性差的物体；不容易受环境电磁场的干扰。

劣势：测距速度不如激光测距和毫米波测距；超声波有一定的扩散角，只能测量距离，不可以测量方位，只能在低速时使用；发射信号和余振的信号都会对回波信号造成覆盖或者干扰，因此在低于某一距离后就会丧失探测功能。

3.3.1.3 激光雷达传感器

原理：激光雷达是将激光束发送到目标，通过接收和反射之间的时间间隔确定到目标的距离，通过几何变换激光束角度获得有关对象位置的信息。用激光雷达进行目标障碍物的检测主要有两种方法。一种是有前验模型的，在已有模型的基础上同时完成障碍物的检测和目标的分类；另一种是无先验模型的，在拟合分离地面信息后从剩余的非地面信息中进行障碍物的分类检测。激光雷达按照计算距离的方式可以分为三角测量和飞行时间测量(TOF)两种；按照探测范围可以分为单线激光雷达与多线激光雷达两种。

适用范围：车载激光雷达的探测距离为150m，三角测距原理的激光雷达只有几米，TOF法测距可达几百米。

优势：探测范围更广，探测精度更高，可以获取比较致密的点云信息，在对环境的感知及对障碍物的检测上有独特优势。

劣势：在雨雪雾霾天、沙尘暴等恶劣天气下不能正常工作，受环境影响大；无穿透能力，探头须完全外露才能达到探测效果，影响车辆外形美观。

3.3.1.4 毫米波雷达传感器

原理：毫米波雷达工作在毫米波段，通常毫米波是指30～300GHz频段(波长为1～10mm)。毫米波雷达传感器由振荡器 (https://www.elecfans.com/tags/振荡器/)产生一个频率随时间逐渐增加的信号，信号遇到障碍物之后反弹回来，其时延是距离与光速比值的二倍。返回波形与发出波形之间存在频率差，此频率差与时延呈线性关系：物体越远，返回的波收到的时间越晚，则其与入射波的频率差值越大。因此，可以通过检测差拍频率的高低判断传感器到障碍物的距离。

适用范围：毫米波雷达的探测距离较长,可以达到200多米。毫米波雷达广泛应用于导弹制导、目标监视和截获、炮火控制与跟踪和雷达测量等方面。

优势：距离远、可靠性高、不受光线、尘埃影响，测量距离比摄像头更长，价格相对激光较为便宜。

劣势：毫米波会在雨、雾和湿雪等高潮湿环境有所衰减；大功率器件和插损的影响会降低毫米波雷达的探测距离；树丛穿透能力差，相比微波，对密树丛穿透力低；元器件成本高，加工精度相对要求高，单片收发集成电路的开发相对迟缓。

### 3.3.2 避障及路径规划算法

3.3.2.1 全局路径规划算法

全局路径规划是在对环境整体布局完全已知的条件下的路径规划方法，意在找出满足某些条件的最优解。全局路径规划算法有很多，大致可分为传统算法、智能算法及二者相结合的混合算法，具体包括A*算法、遗传算法、蚁群算法、粒子群算法等。

3.3.2.1.1 A*算法

A*算法是在Dijkstra算法的基础上加入了启发函数和预估代价的一种启发式算法，广泛应用于静态环境下的最短路径直接搜索。其公式表示为f(n)=g(n)+h(n)，其中，f(n)是从初始点经由节点n到目标点的估价函数，g(n)是在状态空间中从初始节点到n节点的实际代价，h(n)是从n到目标节点最佳路径的估计代价。算法的关键在于估价函数f(n)的选取：设n到目标节点的距离实际值为d(n)，若h(n)≤d(n)，则搜索点数多，搜索范围大，效率低，但仍能得到最优解；若h(n)=d(n)，则搜索将严格沿着最短路径进行，此时的搜索效率是最高的；若h(n)＞d(n)，则搜索的点数少，搜索范围小，效率高，但不能保证得到最优解。

有越来越多的学者对A*算法进行了优化，如陈鑫鹏等提出了等步长分层拓展的方法；刘子豪等结合跳跃点搜索理论，优化了子节点的选择；李世国等采用了双向A*算法，从起始点和目标节点同时相向开始搜索直至重合；唐碧君等为解决传统A*算法使得无人车辆容易出现不必要的转向和与障碍物产生碰撞的问题，提出了改进混合A*算法；闵海涛等根据非结构化环境的特点，提出了全球导航层与局部规划层相结合的环境描述方法和基于非结构化环境中自动驾驶车辆A*算法的改进型局部运动规划算法。改进的算法中，通过设置安全空间避免了轮廓碰撞，在启发式功能设计中考虑了路径曲率的成本。与原始算法相比，它们提高了路径的平滑性，从而使路径更符合车辆运动特点。

3.3.2.1.2 遗传算法

遗传算法的基本思想脱胎于达尔文的进化论和孟德尔的遗传论，其流程框图下图所示。


图13 遗传算法框图与遗传算法的执行过程

假设一个初始解集，将每个解视为染色体不同的个体，将其置于一系列的约束条件之中，按照物竞天择，适者生存的原则，筛选出表现较为良好的个体，将其复制、交叉、变异产生新一代的个体集，通过一代代进化筛选，最终得到最适应约束条件的个体也就是最优解。但是此类算法在环境偏复杂时，结果收敛速度较慢，无法确定精确最优解，算法的参数难以定量等不足。但是它依然具有宽广的前景和很大的潜力，吸引了众多学者展开研究。

3.3.2.1.3 蚁群算法

蚁群算法于1992年被首次提出，其创始人意大利学者Dorigo等在蚂蚁觅食行为中得到灵感，如下图所示。


图14 蚁群迷失行为简图及蚁群系统示意图

蚂蚁在觅食的路径上会留下信息素，当找到食物，蚂蚁原路返回，该路径上的信息素浓度将明显高于其他没有找到食物的路径，后来的蚂蚁选择路径的概率随着信息素浓度的增高而增加，且信息素有挥发性，使得有食物的路径上信息素浓度与没有食物路径上的信息素浓度差距越来越大。而有食物的路径中，路程越短的路径单位时间内通过的蚂蚁越多，信息素浓度越高，导致最终蚂蚁的路径趋向于最近的食物路径。蚁群算法在全局优化方面效果良好，且鲁棒性强，但同时也有计算量大的缺陷，且由于信息素的累计容易导致局部最优解。

蚁群算法也存在多种优化算法，如王苏彧等将传统的定常数信息素挥发因子跟改为随时间变化的服从Laplace分布的信息素挥发因子，加强了算法路径的多样性，保证了结果的最优性；徐玉琼等提出变步长蚁群算法，将传统蚁群算法中的单步长扩展为除了有障碍存在以外的的全局环境选择跳点，该算法收敛速度较之传统算法大幅提高，且在复杂环境下也能有较好的表现；桑和成等提出了转角启发因子，令路径选择的有效性大大提高并引入估价函数思想，对下一节点与目标节点的距离进行评估，缩小了路径搜索范围，提高了算法效率等等。

3.3.2.1.4 粒子群优化法

粒子群优化法起源于人们对鸟类觅食行为的探索，其流程框图如下图所示。

JCGC202205004_02200

图15 粒子群算法框图

将每只鸟看作一个有速度和位置信息的粒子，每个粒子找到食物后将自己的路径信息与同类共享，通过与同类比较，选取更近的路径，多次比较迭代后，得到最优解。粒子群优化算法具有收敛速度快，鲁棒性强，精度高等优点，但也容易造成收敛过早，局部最优解的问题。

粒子群算法也存在一系列的优化算法，如李学军提出了反向学习粒子群的方法应用于机器人的多目标路径选择，该算法模型简单，计算速度较快；付兴武等将粒子群优化算法与天牛须算法结合，将每个粒子加入天牛会对环境进行自我判断的能力，使算法规划效率更高，路径更优；杨红果等将传统粒子群算法与遗传算法相结合，有效克服了传统粒子群算法易于陷入局部最优以及迭代次数多的缺点。

3.3.2.2 局部路径规划算法

局部路径规划属于动态规划，是指无人车辆通过传感器，实时感知环境信息，对局部环境建模，完成从当前节点到下一子节点路径的局部最优化。局部路径规划算法根据其特点可分为采样方法、条件约束法、机器学习法，以下将对滚动窗口算法、人工势场算法、强化学习算法分别进行概括。

3.3.2.2.1 滚动窗口算法

滚动窗口算法是指根据传感器感知环境，通过滚动的方式对路径作出在线规划，每滚动一步（按照上一步的规划路径），探测到新的环境信息，进而对上一步的规划作出反馈并用启发式方法优化下一步子目标的选择，并做出新的局部路径规划。如此循环达到对局部动态环境的实时路径规划效果。该算法计算量较小，对环境较为敏感，可有效避开障碍物，具有实时性。

3.3.2.2.2 人工势场算法

人工势场算法是指人为建立一个虚拟力场，车辆在环境中同时受到障碍物的斥力和目标点的吸引力，车辆受到的力的大小与其同障碍物或目标点的距离负相关，即距离越短，受力越大（如下图所示）。

JCGC202205004_03600

图16 人工势场示意图

在上图所示的人工势场中，无人车辆在合力作用下不断前往下一个目标点，进行运动。人工势场算法存在许多问题，例如在障碍物附近的目标点，其产生的合力几乎为零使得无人车难以到达，陷入局部最优；在经过狭窄路径时易产生左右震荡的问题等。因此人工势场算法不宜用于高自由度下的车辆路径规划问题。但是人工势场算法的简单结构，快速响应，规划路径平滑等特点依然吸引了众多研究学者的探索。

人工势场法的相关优化算法也有许多，例如陈麒杰等提出了改进的人工势场，在斥力函数中加入了和目标点与障碍物之间的距离相关的斥力影响因子，避免了无人机或无人车辆相撞；何乃峰等在斥力场函数中引入位姿阈值增益，利用退火算法原理，当无人车陷入局部最小值时，重构障碍斥力函数，以一定的概率达到全局最优解；李军等将传统斥力场更改为椭圆形使得路径更平滑，建立道路边界斥力场使得车辆不会偏离道路，对移动的障碍添加速度斥力场使得环境更符合实际情况等等。

3.3.2.2.3 基于强化学习的路径规划算法

强化学习是无人车辆通过传感器与环境进行信息交互试错学习，对无人车辆应对不同环境的行为作出奖惩评判，从而不断优化行动方案达到最佳。强化学习可较好地应对复杂动态环境，但其学习能力难以提升，面对复杂环境往往计算收敛速度慢，限制了其实时局部路径规划的实际表现。但强化学习算法需要一定时间的试错与长期的调试，在有限的时间及20分钟内的现场运行中难以实现，因此不适合本次任务的要求。

3.3.2.3 对比分析与总结

综合上述分析，可以发现全局路径规划普遍显示出求解效率较低，易于陷入局部最优的问题，但算法的求解能力与收敛速度是一对相互排斥的性质，因此全局规划的优化改进方法主要集中于在保证算法求解能力的同时提高求解效率，增大求解过程中解的多样性以保证最终解的优良性。上述全局路径规划算法的特点比较及改进方法如下图。

JCGC202205004_03000(2)

图17 全局路径规划算法的优缺点以及其改进方式

局部路径规划的对算法的反应速度要求较高，以至于算法的求解能力较弱或增强求解能力的途径较为困难。但是局部路径规划算法可看做一次次基于当前环境的全局路径规划，将全局路径规划算法同局部路径规划算法相结合，克服求解能力弱的缺点。上述局部路径规划算法的特点比较及改进方法如下图。

图18 局部路径规划算法的优缺点以及其改进方式

避障与路径算法多种多样，仍然有许多本文未列出的经典算法，如Bug法采用发现障碍后绕行的方法寻找路径（如下图），向量场直方图法（VFH）根据当前小车传感器数据对周围环境创建一个极坐标表示的局部地图，神经网络算法以小车当前的方向和速度、传感器的信号作为输入而以下一个目标或者运动方向作为输出，模糊逻辑法将操作经验转换为对应的模糊逻辑语句来控制小车的避障过程，栅格法将整个地图进行栅格划分从而将问题转化为图上起点栅格和终点栅格的最短路径问题，随机法通过在每次小车开到“尽头”时判断是否已经到达终点选择下一步停止或者随机转向等等，各种算法各有优劣，也有不同的应用场景。


图19 Bug1算法与Bug2算法示意图

### 3.3.3 避障及路径规划算法设计注意点

首先，应注意传感器的适用条件。比如红外线会被黑色物体吸收，超声会被海绵吸收，以及红外和激光难以探测透明物体等等。其次，可以采用多种传感器结合互补的方式。理论上没有传感器可以适合于所有情况，因此不妨考虑多种传感方式结合互补，使得小车对环境的感知更加可靠。最后，应注意考虑自身其他配件的影响。比如多个同时工作的超声波传感器，很容易就影响到彼此，需要谨慎考虑。

## 3.4 控制器硬件

可以选用的控制器硬件主要分为CPU、FPGA等。其中CPU的编程调试较为方便，主要通过串行执行，具体包括MCS-51系列、MSP430系列等单片机，STM32、LM3S8962等ARM架构与TMS320F2812等DSP。而FPGA的并发速度快，可靠性好，调试较为困难，具体包括Altera、Xilinx等。除此之外，也有一些其他的控制硬件，性能相对较差且调节较为困难，在此不再赘述。

## 3.5 数据通讯

在数据通讯方面，因小车需要远程无线通信控制，主要可考虑蓝牙、Zigbee、WiFi等方式。

3.5.1 蓝牙

蓝牙模块体积很小、便于集成，功耗低，具有很好的抗干扰能力，在短距离传输场景下较为可靠，蓝牙透传的通信速率较低。可以选用的HC-05模块具备全双工模式，可以实现在发送运行数据的同时接受来自手机的控制信号。

3.5.2 Zigbee

Zigbee是近年来才兴起的一种无线网络通信技术标准，拥有低功耗、低成本、短时延、安全性高等等优点，支持多节点之间的通信，但是传输速率较低。

3.5.3 WiFi

WiFi与蓝牙技术一样同属于短距离无线技术，拥有覆盖范围广，无需布线，传输速度快的优势，在当前的移动终端的联网方面应用广泛，但透传的WiFi串口协议速率容量相对较低。

## 3.6 电机与驱动

### 3.6.1 电机

在电机选用上，常用的电机包括航模舵机、直流电机、永磁同步电机、音圈电机、步进电机、交流异步电机等，其中前两种在智能小车上较常用。具体而言，航模电机可以进行较高精度的角度控制，实现自闭环控制，应用较为简单；直流电机适合连续旋转，可以通过电流驱动器与控制器实现角度与速度控制，较复杂；永磁同步电机适合长行程精密运动系统的直接出力；音圈电机适合微行程精密运动系统；步进电机适合开环的较高精度控制；交流异步电机需要通过变频驱动器进行速度控制，在力矩较大时往往与减速器共同使用，在智能车中应用较多。

### 3.6.2 驱动方式

在驱动方式上，常用驱动方式包括单驱动、两轮驱动与四轮驱动，而两轮驱动又分为前轮驱动、后轮驱动，四轮驱动又分为全时四驱、分时四驱与适时四驱。

单驱动方式一般有一个驱动兼转向轮和两个分布在车体轴线两边的固定从动轮。它对地表面要求一般，适用于广泛的环境和场合。

前轮驱动汽车是指发动机的动力直接传递给前轮从而带动车辆前进的驱动方式。前轮驱动的机械组件少而且集中，可以减轻重量，降低造价；由于动力直接传动，不需要传动轴，减少了损耗，运转效率更高，空间的利用上也有更多的余地。

后轮驱动汽车是指发动机的动力通过传动轴传递给后轮，从而推动车辆前进的驱动形式。后轮驱动的操控性好，后轮负责驱动，简化了操纵机构的布局和转向机构的结构，令前轮可专注于转向工作，因此转向时的车辆反应更加敏捷，重心靠后也让后驱车在行驶过程中可以更好的控制车身姿态任意变化。

全时四驱不需要驾驶人选择操作，前后车轮永远维持四轮驱动模式，行驶时将发动机输出扭矩按50:50设定在前后轮上，使前后排车轮保持等量的扭矩。全时四驱是公路过弯极限最高的传动方式，它可以实现车辆高速过弯时每个车轮分配到最佳的驱动力和追求过弯极限。

分时驱动是指驾驶者可以在两驱和四驱之间手动选择的四轮驱动系统，由驾驶员根据路面情况，通过接通或断开分动器来变化两轮驱动或四轮驱动模式。分时四驱技术很成熟，结构也比较简单，灵活性和可靠性好，加上其不用装配中央差速锁，成本要比全时四驱低得多。

适时四驱的车辆可以通过电脑来控制选择适合当下情况的驱动模式。适时四驱的结构比全时四驱简单得多，不仅可以有效降低成本，还有利于降低整车重量。由于可以有效避免特殊情况下后轮抓地力不足的弊端，适时四驱适合于前横置发动机前驱平台的车型配备。

# 4. 原理设计方案

在进行需求分析、任务分解与文献调研后，我们将初步设计方案整理如下：

## 4.1 车架总体


在运动方式上，考虑到本次实验场地地形较为平坦，我们计划选用轮式移动这一性价比较高的方案。在车架布局上，我们计划使用四个麦克纳姆轮，同时，由于小车尺寸的限制及需要装载多种元器件及电子线路的要求，我们计划将小车总体分为三层，底层主要放置机械臂基座、电源电池组、电机及其驱动模块、超声波传感器等，中间层放置遥控用的摄像头、单片机、电压转换模块、蓝牙模块等，最上层面积较小，仅放置前置的图像识别摄像头和WiFi模块。

图20 初步车架总体设计方案

## 4.2 抓取结构

抓取装置的“钳爪”需要和货物尺寸匹配，同时要考虑抓取时的姿态，保证足够的压力与摩擦力，避免抓取过程中掉落。考虑到取物前后图像识别的需要，以及超声波传感器的位置，需要使抓取结构尽量短小，且抓取后不能遮挡摄像头与传感器。因此，综合考虑机械手爪、吸盘与仿生机械手三种抓取结构后，我们计划选用最简单的二自由度机械臂，用两台舵机控制手爪开合与机械臂角度完成抓取。具体而言，机械臂的转动轴与小车横向平行，抓取货物时在小车前方，将货物装上小车后将旋转至小车结构中，避免了对于摄像头收集图像信息的干扰。在具体的结构设计上，对于手爪的每个爪体用两个转轴连接，实现转动完成抓取。上部的轴一端固定，一端与手爪连接，下部轴一端与手爪连接，一边为齿轮，两侧由一个舵机驱动，通过齿轮传动同时驱动两个手爪。


图21 机械手爪结构设计

## 4.3 任务所用传感器

在任务1（循迹部分）中，综合考虑红外传感器、线阵CCD、摄像头三种传感器后，我们计划选用OpenMV摄像头实现循迹功能。这是因为摄像头相比于红外传感器具有更强的前瞻能力，相比于线阵CCD具有更强的纠偏能力和较短的图像获取时间，且循迹过程中不需要较大的视场，因此选用摄像头作为寻线过程的传感器更合适。另外，了解到OpenMV具有更多的资源与更强大的功能，我们计划选用OpenMV以增强可实现性。

在任务2（避障任务）中，综合考虑红外、超声波、激光雷达、毫米波雷达、摄像头五种避障传感器后，我们计划选用OpenMV作为传感器，用IMU确定初始位姿，并用超声波传感器作为辅助。如此可以充分利用OpenMV获得的二维图像信息与较好的前瞻性，并用超声波测量小车其他方向距障碍物的距离作为补充。在实现方式上，我们初步打算利用IMU确定初始位姿后规定初始方向并在相应模型中建立对应的引力，通过随机算法与人工势场法的加权实现小车前进方向的实时更新，之后会在实现中具体论证可行性。若利用OpenMV进行避障任务遇到较大阻碍，也可选用五个超声传感器（前方左、中、右各一个，后方两侧各一个）完成避障功能。

## 4.4 控制器硬件

硬件的选择主要基于计算能力和编程难易程度，具体而言，FPGA的并发速度快，可靠性好，但调试困难，其他传统形式则难度更大，相比之下，采用CPU会简便许多。在智能小车的循迹、避障任务中，显然对于计算力和内存要求最高的是图像处理。STM32具有一定的图像处理能力，但在这一领域树莓派的计算能力更好且同时支持OpenCV库，即可采用一些现有的函数对于采集的图像进行处理，但树莓派的开发环境搭建更为繁琐，STM32更适于硬件开发。考虑到OpenMV作为传感器则可以替代树莓派进行图像处理相关的工作，我们初步决定开发时以STM32为主，辅助OpenMV图像处理模块作为上位机。

## 4.5 数据通讯

考虑到小车需要进行远程无限通信与控制，因此需要寻找无线通讯的手段。在比较蓝牙、Zigbee、WiFi三种无线通讯方式后，我们计划选用更加熟悉的HC-05蓝牙串口模块作为单片机与移动终端的通讯方式，完成指令数据传输、状态参数传输、舵机命令传输的任务。而对于摄像头向PC机实时传输图像进行遥控，蓝牙和Zigbee的传输速率不足，需要使用WiFi模块进行传输。

## 4.6 电机与驱动

在电机选型上，由于控制车轮转动对于转动角度的控制精度要求很低，但对于电机功率与扭矩的要求较高，因此直流电机适合连续旋转、控制逻辑简单的特点符合我们的要求。在机械臂以及相机角度的控制上对于精度要求高，但对速度要求不高，且有小体积的需求，因此航模舵机更加合适。

在驱动方式上，虽然四驱看起来较为笨重，但考虑到保证能够完成任务的要求，需要在控制过程中有更大的发挥空间，因此我们计划选择操控性更好的四驱结构。在车轮驱动上，我们计划选择L298N电机驱动模块，每个可以驱动两个电机，因此用两个驱动模块完成车轮驱动。

## 4.7 总电源与二次电源

表2 各元器件所需电压

元器件 | 所需电压
25GA370直流电机 | 12V
STM32F103单片机 | 5V
HC-05蓝牙串口模块 | 5V
L298N电机驱动模块 | 5V
OpenMV图像处理模块 | 5V
HC-SR04超声波传感器 | 5V
SG90舵机 | 5V
MG995舵机 | 5V
JY901S九轴IMU | 3.3V

经过调研后，我们将需要用到的各元器件所需电压整理如上表。由于需求主要为直流电源，而直流电机25GA370的额定工作电压为12V，因此我们选取实验室提供的由干电池串联而成的12V直流电源作为总电源，考虑到其他各个元件与模块的用电需求，还需要加入二次电源，即12V转3.3V和12V转5V的二次电源模块，即可满足电源电压的要求。

参考文献

[1] 何武剑,邱浩峰,曲晓坤,陈迦勒,孙俊巧,余腾龙.智能小车发展应用研究[J].河南科技,2022,41(11):26-29.DOI:10.19968/j.cnki.hnkj.1003-5168.2022. 11.005.

[2]张忠民、郑仁辉：《基于模糊PID的麦克纳姆轮移动平台的控制算法》，《应用科技》，2017年第06期。

[3]高至、李传昌、梁世伟、兰晔、李岳洪：《智能车路径识别及转向控制的研究与实现》，《南方农机》，2019年第12期。

[4]赵艳娥、张建武：《轮毂电机驱动电动汽车电子差速系统研究》，《系统仿真学报》，2008年总第18期。

[5]杨俊驹、林睿、王振华、孙立宁：《轮式移动机器人运动控制系统研究与设计》，《现代电子技术》，2016年第02期。

[6]许皓博.自动循迹跟随智能小车设计[J].数字通信世界,2022(01):132-134+137.

[7]洪一民,钱庆丰,章志飞.基于STM32的智能小车循迹避障测距的设计[J].物联网技术,2022,12(01):12-13+17.DOI:10.16667/j.issn.2095-1302.2022.01.004.

[8]王信乐,刘祚时.基于线性CCD的智能小车循迹系统设计与研究[J].制造业自动化,2020,42(08):79-84.

[9]余世干,张廉洁,张旭东,戎强强.基于线性CCD检测的寻线智能车设计与实现[J].赤峰学院学报(自然科学版),2015,31(19):65-67.DOI:10.13398/j.cnki.issn1673-260x.2015.19.025.

[10]毛祖光,杨洁.自循迹智能小车控制系统的设计与实现[J].科技风,2022(14):7-9+69.DOI:10.19392/j.cnki.1671-7341.202214003.

[11]冯谣.基于CCD摄像头智能循迹小车的研究与开发[J].浙江交通职业技术学院学报,2018,19(Z1):16-20.

[12]张迪.智能车中摄像头的图像畸变矫正[J].信息系统工程,2012(07):82-84.

[13]周阳,雷鹏.飞思卡尔智能车竞赛中赛道曲率的单点求法[J]. 中国电子商务, 2013(7):1.

[14]蒋旭,吴涛.两点算法求智能车赛道曲率[J].新技术新工艺,2014(04):32-33.

[15]刘得权,李政清,王榜,秦家屹,智慧超,张雪峰,颜微.智能小车环境感知系统的设计[J].山西电子技术,2022,(01):16-18.

[16]吴慧珍.智能车载避障算法研究[D].中国矿业大学,2021.DOI:10.27623/d.cnki.gzkyu.2021. 002921.

[17]程天明.机器人定位与避障的关键技术研究[D].广东工业大学,2021.DOI:10.27029/d.cnki. ggdgu.2021.002053.

[18]王涛,黎玉康,刘文学.无人车辆路径规划算法发展现状[J].舰船电子工程,2022,42(05): 15-22.

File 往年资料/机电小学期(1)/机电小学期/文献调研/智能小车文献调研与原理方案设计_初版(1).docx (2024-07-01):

智能小车文献调研与原理方案设计

1. 引言

为完成《机电系统设计实践》课程的主要任务，将智能小车更好地予以实现，笔者将通过需求分析、任务分解、文献综述初步明确智能小车的要求、相应细化的问题，了解目前的相关技术进展，并据此进行初步的原理方案设计。

智能小车是计算机、传感、通信、人工智能、自动控制等技术的集合，将环境感知、自动决策、自动驾驶等功能融为一体，是典型的现代高新技术结合体。近年来，智能小车在应用和技术上都取得了很大的进步，它也因可以搭载多种模块且具有强大的环境适应能力，被广泛地应用于各领域。

本文中所实现的智能小车指能够自主移动并实现在寻迹场景与避障场景中自主完成抓取、运输和卸载货物工作的AGV轮式小车。在对智能小车任务进行需求分析与任务分解后，本文将从机械结构及运动控制、循迹传感器及算法、避障传感器及算法三部分进行文献调研并综述。之后，本文将通过文献调研与需求分析所得结果，进行初步方案原理的设计。

2. 需求分析与任务分解

课程的总体任务为“设计并实现一个机电系统，在2种不同场地，分别按规定路线自助寻线与无固定路线自助避障，将给定货物从一个指定位置运输到另一指定位置”，可将此任务分解为车架主体、抓取结构、任务所用传感器、控制器硬件、数据通讯、电机与驱动、总电源与二次电源七方面来逐个分析。

车架主体

车架整体尺寸：在自助避障任务中，障碍物间的间距不小于350mm，因此，小车的宽度应小于350mm并留出适量裕度。

车架空间结构：由于小车的占地面积不能过大，且需要在车架上装配多种元器件和电子线路，因此可以考虑将小车做成二层或三层结构。

驱动与转弯方式：驱动方式上，可以选择仅使用两轮或三轮并用两轮驱动，也可以选择使用四轮并采用四轮驱动或者后轮驱动，几种方式各有优劣，将在后文中进行分析比较。转弯方式上，可以采用普通轮并通过差速转向或者偏转前轮转向予以实现，也可以采用麦克纳姆轮通过4个轮子不同转速的相互配合来实现全向移动，其优劣与特点也将在后文中进行比较。

抓取结构

机械爪及舵机：

任务所用传感器

控制器硬件

数据通讯

电机与驱动

总电源与二次电源

3. 文献综述
  3.1 机械结构及运动控制
    3.1.1 运动方式

现有的可以运动方式主要有三种，即轮式、步行式与履带式，下文将分别综述二者的实现方式及特点。

      3.1.1.1 轮式运动

轮式移动的AGV小车可以分为三种：两轮差速移动AGV小车、带带舵轮的四轮移动AGV小车和三轮移动AGV小车。两轮差速移动AGV小车具有节省空间、机动性好等特点，被广泛应用在各大企业的生产工厂内。三轮移动和四轮移动的AGV小车则能够以轮式移动为特征，与步行、爬行或是其他非轮式的移动机器人相比，更加快捷，工作效率也更高。另外还具有无人值守自动化搬运、承载重量大、结构简单、可控性强、安全性好等优点。与物料送中常用的堆垛机、单轨小车、传送带、传送链，AGV的活动区域不受场地、道路和空间的限制。因此，在自动化物流系统中，最能充分地体现其自动性和柔性，实现高效、经济、灵活的无人化生产。

对于四轮式AGV小车，又可以细分为前驱、后驱以及四驱。前驱或者后驱由于驱动电机数量少，能够增加内部空间，在空间的利用上有更多的余地，减轻小车重量，耗能低。但是由于前后配重不均匀，另一侧的车轮在行进过程中容易失去抓地力，出现转向不足或者转向过度的问题，对于操控性有负面影响。四驱的AGV小车则前后配重相对均匀，同时由于四轮均能够获得动力，行进过程操控性更好，容错性更高，更为稳定，在路面状况较为复杂时也拥有更好的适应能力，但是会导致小车自重较大，行动的灵活性受到影响，耗能也更大。


图1 轮式小车

      3.1.1.2 步行式运动

步行式机器人分为单腿式、双腿式和多腿式等等类别。

首先，足式机器人的运动轨迹是一系列离散的足印,轮式和履带式机器人的则是条条连续的辙迹。崎岖地形中往往含有岩石、泥土、沙子甚至峭壁和陡坡等障码物可以稳定支撑机器人的连续路径十分有限,这意味着轮式和履带式机器人在这种地形中已经不适用,而足式机器人运动时只要离散的点接触地面,对这种地形的适应性较强,正因为如此,足式机器人对环境的破坏程度也较小。

第二,足式机器人的腿部具有多个自由度,使运动的灵活性大大增强。它可以通过调节腿的长度保持身体水平,也可以通过调节腿的伸展程度调整重心的位置,因此不易翻倒,稳定性更高。同时，机器人的身体可以平稳地运动而不必考虑地面的粗糙程度和腿的放置位置。当机器人需要携带科学仪器和工具工作时,首先将腿部固定,然后精确控制身体在三维空间中的运动, 就可以达到对对象进行操作的目的。


图2 步行式机器人

      3.1.1.3 履带式运动

履带车对地面单位压力小，下陷小，附着能力强，行驶通过能力强。一般按行驶系结构可分为前桥（从动桥）装雪橇或车轮、后桥装履带的半履带式，前后桥都装履带的全履带式和可互换使用车轮、履带的车轮-履带式三种类型。

履带能够使受力面积加大，增大摩擦，抓地力变好，相对地面的压强减小，不容易造成陷轮。并且结构简单，结实耐用。而且履带板上有花纹，并能安装履刺，所以在雨、雪、冰或上坡等路面上能牢牢地抓住地面，不会滑转。履带适合在条件不好的环境下作业。例如雪地、山坡、草地等。但是在生产成本上，履带车要比轮式车高很多。


图3 履带式小车

    3.1.2 转向方式

在目前设计的智能小车中，转向多采用普通轮并使用差速法实现，也可以通过全向轮（即麦克纳姆轮）实现。

      3.1.2.1 普通轮（差速法）

参考阿克曼（Ackerman）转向几何学原理，即在汽车转向时4个轮胎都近似围绕一个中心点旋转以保证汽车的行驶稳定性。把汽车的形心作为质心，并且忽略路面情况变化等的影响，可得出四轮驱动差速转向小车的运动学模型如下图所示。


图4 四轮驱动差速转向小车的运动学模型

α1 和 α2 分别为前左轮和后左轮，前右轮和后右轮的转角；2L 为左右轮距离；2K 为前后轮轴距；v和 ω 分别为车子质心的线速度和角速度，V1 ，V2 ，V3 ，V4分别为各个轮中心的实际运动方向。由此可以求出各速度和转角的关系。


      3.1.2.2 麦克纳姆轮

随着现代控制技术和计算机技术的发展，移动机器人在越来越多的领域开始发挥至关重要的作用，作为移动机器人的关键部件，移动平台可以保证机器人的移动性和稳定性，成为了机器人领域的研究重点。其中麦克纳姆轮移动平台因具有平面上3个自由度的移动能力而逐渐受到了更多的关注。然而麦克纳姆轮移动平台的轮子并不能够直接转向，它是依靠4个轮子各自不同转速的相互配合来实现全向移动，因此每一个轮子的运动都对整体的运动方向和速度大小有着很大的贡献。

全向轮又被称作麦克纳姆轮，其具体结构设计如图1。可以看出它与普通轮之间的主要区别就在于它的圆周上分布有若干数量的辊子，这些辊子的轴线与轮子的轴线呈一定的夹角（本文所采用的麦克纳姆轮的偏置角为 45°），辊子的外廓线所形成的包络面和轮的原始圆周面重合，这样保证了辊子能与地面一直保持接触[2]。这些辊子还可以自由转动，这使得轮子只受到地面对辊子轴向上的力，而地面对辊子的圆周力则变为了滚动摩擦可以近似看为零。因此，轮子与地面的接触力不再是沿轮子的圆周方向，而是与它呈一定的夹角，所以这种轮子可以在一个方向上受到摩擦力的驱动，而另一个方向上却能够自由移动。由4个这样的轮子便可以组合出不同的受力情况，从而使移动平台可以实现平面上3个自由度的移动。通过对于单轮的运动学分析可以求得全向轮运动的雅各比矩阵，通过控制四个轮的转速来控制运动平台的平动与转动速度。

图中R 表示全向轮轴心到轮外廓圆周面的距离即轮的半径；Vix为第i轮沿X轴方向的分速度；Viy为第i轮沿Y轴方向上的分速度，Vs为辊子的速度；辊子轴线与全向轮轴线夹角为α；ωi为全向轮绕轮轴的转速。i=1、2、3、4，分别代表了左前轮、右前轮、左后轮、右后轮。联立可得矩阵方程：

V_i =(R/4)[1, 1, 1tanα, -tanα, -tanα-1/(l_0), 1/(l_0), -1/(l_0) 1tanα1/(l_0)][ω_1 ω_2 ω_3 ω_4 ]

式中： l_0 =W+Lcosα ，其中 W 为移动平台宽度，L 为其前后轮轴距；而α取 45°，其正负号已被提出，不再区分正负。其逆运动学方程为：

[ω_1 ω_2 ω_3 ω_4 ]=K[V_y V_x ω]=(1/R)[1, cotα, -l_0 1, -cotα, l_0 11, -cotαcotα, -l_0 l_0 ][V_y V_x ω]

    3.1.3 机械臂末端执行器

机械臂的末端处理器可以采用机械手爪、磁力/真空吸盘、仿生多指灵巧手等结构，其原理及特点如下。

3.1.3.1 机械手爪

机械手爪通常采用气动、液动、电动和电磁来驱动手指的开合。气动手爪应用广泛，气 动手爪结构简单、成本低，容易维修，开合迅速，重量轻。但空气介质的可压缩性使爪钳位 置控制比较复杂，稳定性不足，可靠性存疑。液压驱动手爪成本较高。电动手爪的手指开合电动机控制与机器人控制可以共用一个系统，但是夹紧力比气动手爪、液压手爪小。电磁手爪控制信号简单，但是电磁夹紧力与爪钳行程有关，只用在开合距离小的场合。液压手爪抓取力大、提升过程可靠、控制精准、动作灵敏，但由于夹紧力大，对于被夹物品的材料刚性有一定的要求。


图5 机械手爪

3.1.3.2 磁力/真空吸盘

磁力吸盘有电磁吸盘和永磁吸盘两种。磁力吸盘的特点：体积小，自重轻，吸持力强， 可在水里使用。磁力吸盘广泛应用于钢铁、机械加工、模具、仓库等搬运吊装过程中对块状、 圆柱形导磁性钢铁材料工件的连接，可大大提高工件装卸、搬运的效率，是工厂、码头、仓 库、交通运输等行业最理想的吊装工具。但是对所抓取的物品有磁性的要求。

真空吸盘原理简单，操作相对容易，但是前提是要保证所抓取物品表面足够平整光滑，此外还需要注意对于吸盘盘面的清洁与保护，防止污渍与腐蚀等等，对于后期维护保养的要求较高。


图6 磁力吸盘

3.1.3.3仿生多指灵巧手

简单的夹钳式取料手不能适应物体外形的变化，不能使物体表面承受比较均匀的夹持力， 因此，无法满足对复杂形状、不同材质的物体实施夹持和操作。为了提高机器人手爪和手腕 的操作能力、灵活性和快速反应能力，使机器人能像人手一样进行各种复杂的作业，如装配作业、维修作业、设备操作以及机器人模特的礼仪手势等，就必须有一个运动灵活、动作多样的灵巧手。

多关节柔性手能针对不同外形物体实施抓取，并使物体表面受力比较均匀，每个子指由多个关节串接而成。手指传动部分由牵引钢丝绳及摩擦滚轮组成。每个指由2根钢丝绳牵引，一侧为握紧，另一侧为放松。驱动源可采用电机驱动或液压、气动元件驱动。柔性手腕可抓取凹凸外形物体并使其受力较为均匀。柔性材料做成的柔性手一端固定，一端为自由的双管合一的柔性管状子爪。当一侧管内充入气体（液体），另一侧管抽出气体（液体）时，形成压力差，柔性手爪就向抽空侧弯曲。此种柔性手适用于抓取轻型、圆形物体，如玻璃器皿等。


图7 仿生多指灵巧手

  3.2 循迹传感器及算法
    3.2.1 红外传感器

红外发射管竖直发射出红外线，红外接收管接收反射的红外线，用光电传感器或灰度传感器可以将接收到的红外线光信号转化成电信号。红外射线照在白色地面上，红外传感器接收到反射回的红外线比较强，转化的电信号也比较强；若红外线照在黑色引导线上，这时反射回的红外线的强度较弱，转化为的电信号也较弱。小车的循迹通过红外传感器接收到的信号强弱来控制，通过转化为的电信号强弱差异，就可以判断并调整小车的行驶路线。

查看源图像

图8 红外传感器（左） 五路红外循迹模块（右）

以五路红外循迹模块为例，其控制算法如下表所示：

表1 五路红外循迹模块控制算法示例表

控制流程大致如下：


图9 五路红外循迹控制流程

红外传感器具有灵敏度高、体积小、易于安装等优点，但由于在循迹模块中其数量通常较少，因此该方法对道路的前瞻性不强，循迹效率不高。

    3.2.2 线阵CCD

图像信息采集时,单片机的端口与CCD的图像灰度信息输出引脚相连,线阵CCD是单行采集图像的,并且采集回来的数据是灰度值,对灰度值进行二值化和滤波处理后,最终可以确定跑道的路况情况。

滤波处理多采用时域滤波法，可以采取平均值滤波、中值滤波、限值滤波与滑动平均值滤波等算法，以对数据进行降噪处理。考虑到CCD图像的畸变视角的变化以及环境的影响，阈值的确定通常采用动态阈值法，可以通过取平均电压值、max与min的均值、大津算法等方法求得阈值。此外, 针对每行中的孤立噪点, 可以采用计数法排除。

在对图像进行上述处理后，可以通过跟踪引线的黑线提取算法来提取轨迹线。如果连续黑点数小于某个阈值时, 认为是噪声影响, 而非实际的黑线, 从而可以减少误判概率. 在完成轨迹线的提取后，通过计算可以得出当前小车的方向与黑色引导线之间的位置偏差，接着将此位置偏差信号输入到闭环位置控制系统，经过PID闭环位置控制算法进行调节，将调节后的信号再输入到驱动控制模块，实现对电机在速度上的控制，使小车沿黑色引导线行进。

线阵CCD的优点是路径分辨率高，前瞻性较强，可以更远更早地感知路径的变化，在小车本体跑偏之前修正行进方向，并且可以实时地监控路径的位置，及时纠偏。但此方法的图像获取时间较长，测量效率较低，并且图像精度可能会受扫描运动精度的影响。

    3.2.3 摄像头

由于摄像头提供的图像信息较多、较复杂，因此在对图像信息进行处理时，首先要对图像进行有效部分提取, 提取出感兴趣区域后，对图像从左到右、从上到下进行隔行扫描, 并读取扫描的每个像素点的灰度值，以此为依据进行分割从而提取出循迹小车所在的赛道信息。分割阈值的选择一般也采取动态阈值法，可以从最低灰度等级向高灰度等级进行遍历, 找到第一个灰度等级对应的像素概率为零的灰度级作为最后阈值。在获得赛道信息后，可以根据小车的具体偏移量利用PD控制算法来计算舵机的转角，再利用PID算法闭环调节小车的速度。

由于摄像头与地面之间存在俯角,导致采集到的图像并不是一个方形区域,而是一个近处区域小、远处区域大的梯形区域,图像出现失真。


图10 梯形失真示意图

对于纵向畸变的矫正，通常采用非均匀行采集的算法，其坐标变换表达式为：y=vd。其中d表示两行采样之间的间隔。对于横向畸变，矫正后坐标系之间的变换公式为

x=(CD)/(N-1)(u-N/2) ，式中CD表示视角的底部宽度，N表示总列数。


图11 非均匀行采样示意图

对于赛道曲率的计算有多种算法，最简单的一种方法是利用 q=|(x_3 -x_2 )-(x_2 -x_1 )| 来计算，式中 x_1 、 x_2 和 x_3 为3个实际距离相等的行的黑线位置。赛道曲率还可以用两点法和三点法计算，三点法计算的本质是求三角形的外接圆半径，但往往需要对图像的畸变进行矫正；对于两点法，如果智能车在赛道中心线上，则有 k=(2l_(BC))/(l_(AB)^2 +l_(BC)^2) ；如果小车不在赛道中心线上，则有


其中， A_1 为智能车的左偏移点, 偏距为 l_(AA1) , 曲率为 k_1 ； A_2 为智能车的右偏移点，偏距为 l_(AA2) , 曲率为 k_R 。


图12 小车在赛道中心线上（左） 小车不在赛道中心线上（右）

采用摄像头循迹可以获得二维的图像信息，在前瞻性和纠偏能力上比线阵CCD更优，不过由于其像元数总数多，但每行的像元数比线阵少，因此其图像分辨率比线阵CCD要低，不适用于要求视场大、图像分辨率高的情形。

  3.3 避障传感器及算法
    3.3.1 常见避障传感器

3.3.1.1 红外避障传感器

原理：红外避障主要是以红外测距传感器为主。红外测距都是采用三角测距的原理。红外发射器按照一定角度发射红外光束，遇到物体之后，光会反向回来，检测到反射光之后，通过结构上的几何三角关系，就可以计算出物体距离D。

适用范围：可通过电位器旋钮调节探测距离，有效距离范围0~20cm，顺时针调电位器，检测距离增加，逆时针调电位器，检测距离减少。红外避障传感器广泛应用于及机器人避障、避障小车、流水线计数及黑白线寻迹等众多场合。

优势：结构简明，便于装配，成本低廉，反应灵敏，便于近距离路面情况的检测，抗干扰能力强，不会因为周围环境的差别而产生不同的结果。

劣势：只能对路面情况做简单的黑白判别，检测距离和精度有限，传感器高度位置的差异可能会对其检测造成干扰。

3.3.1.2 超声波避障传感器

原理：超声波测距的原理比红外线更加简单，因为声波遇到障碍物会反射，而声波的速度已知，所以只需要知道发射到接收的时间差，即可轻松计算出测量距离，再结合发射器和接收器的距离，就能算出障碍物的实际距离。

适用范围：作用距离一般在5-10m之间，但是会有一个最小探测盲区，一般在几十毫米。由于需要主动发射声波，因此太远的障碍物会使精度随着声波的衰减而降低，不适合用超声波避障传感器。此外，对于海绵等吸收声波的物体或者在大风干扰的情况下，超声波将无法工作。超声波避障传感器是移动机器人，AGV,无人机，汽车避障中常用的传感器。

优势：结构简单，制造方便，成本较低；超声波对雨、雪、的穿透力强，可以在恶劣天气下工作；超声波对光照和色彩不敏感，可以用于识别透明以及反射性差的物体；不容易受环境电磁场的干扰。

劣势：测距速度不如激光测距和毫米波测距；超声波有一定的扩散角，只能测量距离，不可以测量方位，只能在低速时使用；发射信号和余振的信号都会对回波信号造成覆盖或者干扰，因此在低于某一距离后就会丧失探测功能。

3.3.1.3 激光雷达传感器

原理：激光雷达是将激光束发送到目标，通过接收和反射之间的时间间隔确定到目标的距离，通过几何变换激光束角度获得有关对象位置的信息。用激光雷达进行目标障碍物的检测主要有两种方法。一种是有前验模型的，在已有模型的基础上同时完成障碍物的检测和目标的分类；另一种是无先验模型的，在拟合分离地面信息后从剩余的非地面信息中进行障碍物的分类检测。激光雷达按照计算距离的方式可以分为三角测量和飞行时间测量(TOF)两种；按照探测范围可以分为单线激光雷达与多线激光雷达两种。

适用范围：车载激光雷达的探测距离为150m，三角测距原理的激光雷达只有几米，TOF法测距可达几百米。

优势：探测范围更广，探测精度更高，可以获取比较致密的点云信息，在对环境的感知及对障碍物的检测上有独特优势。

劣势：在雨雪雾霾天，沙尘暴等恶劣天气不能正常工作，受环境影响大；无穿透能力，探头须完全外露才能达到探测效果，影响车辆外形美观。

3.3.1.4 毫米波雷达传感器

原理：毫米波雷达工作在毫米波段。通常毫米波是指30～300GHz频段(波长为1～10mm)。毫米波雷达传感器由振荡器 (https://www.elecfans.com/tags/振荡器/)产生一个频率随时间逐渐增加的信号，信号遇到障碍物之后反弹回来，其时延是距离与光速比值的二倍。返回波形与发出波形之间存在频率差，此频率差与时延呈线性关系：物体越远，返回的波收到的时间越晚，则其与入射波的频率差值越大。因此，可以通过检测差拍频率的高低判断传感器到障碍物的距离。

适用范围：毫米波雷达的探测距离较长,可以达到200多米。毫米波雷达广泛应用于导弹制导、目标监视和截获、炮火控制和跟踪和雷达测量等方面。

优势：距离远、可靠性高、不受光线、尘埃影响，测量距离比摄像头更长，价格相对激光较为便宜。

劣势：毫米波会在雨、雾和湿雪等高潮湿环境有所衰减；大功率器件和插损的影响会降低毫米波雷达的探测距离；树丛穿透能力差，相比微波，对密树丛穿透力低；元器件成本高，加工精度相对要求高，单片收发集成电路的开发相对迟缓。

    3.3.2 避障及路径规划算法

3.3.2.1 全局路径规划算法

全局路径规划是在对环境整体布局完全已知的条件下的路径规划方法，意在找出满足某些条件的最优解。全局路径规划算法有很多，大致可分为传统算法、智能算法及二者相结合的混合算法，具体包括A*算法、遗传算法、蚁群算法、粒子群算法等。

3.3.2.1.1 A*算法

A*算法是在Dijkstra算法的基础上加入了启发函数和预估代价的一种启发式算法，广泛应用于静态环境下的最短路径直接搜索。其公式表示为f(n)=g(n)+h(n)，其中，f(n）是从初始点经由节点n到目标点的估价函数，g(n）是在状态空间中从初始节点到n节点的实际代价，h(n）是从n到目标节点最佳路径的估计代价。算法的关键在于估价函数f(n）的选取：设n到目标节点的距离实际值为d(n)，若h(n)≤d(n)，则搜索点数多，搜索范围大，效率低，但仍能得到最优解；若h(n)=d(n)，则搜索将严格沿着最短路径进行，此时的搜索效率是最高的；若h(n)＞d(n)，则搜索的点数少，搜索范围小，效率高，但不能保证得到最优解。

有越来越多的学者对A*算法进行了优化，如陈鑫鹏等提出了等步长分层拓展的方法；刘子豪等结合跳跃点搜索理论，优化了子节点的选择；李世国等采用了双向A*算法，从起始点和目标节点同时相向开始搜索直至重合；唐碧君等为解决传统A*算法使得无人车辆容易出现不必要的转向和与障碍物产生碰撞的问题，提出了改进混合A*算法；闵海涛等根据非结构化环境的特点，提出了全球导航层与局部规划层相结合的环境描述方法和基于非结构化环境中自动驾驶车辆A*算法的改进型局部运动规划算法。改进的算法中，通过设置安全空间避免了轮廓碰撞，在启发式功能设计中考虑了路径曲率的成本。与原始算法相比，它们提高了路径的平滑性，从而使路径更符合车辆运动特点。

3.3.2.1.2 遗传算法

遗传算法的基本思想脱胎于达尔文的进化论和孟德尔的遗传论，其流程框图下图所示。


图13 遗传算法框图与遗传算法的执行过程

假设一个初始解集，将每个解视为染色体不同的个体，将其置于一系列的约束条件之中，按照物竞天择，适者生存的原则，筛选出表现较为良好的个体，将其复制，交叉，变异产生新一代的个体集，通过一代代进化筛选，最终得到最适应约束条件的个体也就是最优解。但是此类算法在环境偏复杂时，结果收敛速度较慢，无法确定精确最优解，算法的参数难以定量等不足。但是它依然具有宽广的前景和很大的潜力，吸引了众多学者展开研究。

3.3.2.1.3 蚁群算法

蚁群算法于1992年被首次提出，其创始人意大利学者Dorigo等在蚂蚁觅食行为中得到灵感，如下图所示。


图14 蚁群迷失行为简图及蚁群系统示意图

蚂蚁在觅食的路径上会留下信息素，当找到食物，蚂蚁原路返回，该路径上的信息素浓度将明显高于其他没有找到食物的路径，后来的蚂蚁选择路径的概率随着信息素浓度的增高而增加，且信息素有挥发性，使得有食物的路径上信息素浓度与没有食物路径上的信息素浓度差距越来越大，而有食物的路径中，路程越短的路径单位时间内通过的蚂蚁越多，信息素浓度越高，导致最终蚂蚁的路径趋向于最近的食物路径。蚁群算法在全局优化方面效果良好，且鲁棒性强，但同时也有计算量大的缺陷，且由于信息素的累计容易导致局部最优解。

蚁群算法也存在多种优化算法，如王苏彧等将传统的定常数信息素挥发因子跟改为随时间变化的服从Laplace分布的信息素挥发因子，加强了算法路径的多样性，保证了结果的最优性；徐玉琼等提出变步长蚁群算法，将传统蚁群算法中的单步长扩展为除了有障碍存在以外的的全局环境选择跳点，该算法收敛速度较之传统算法大幅提高，且在复杂环境下也能有较好的表现；桑和成等提出了转角启发因子，令路径选择的有效性大大提高引入估价函数思想，对下一节点与目标节点的距离进行评估，缩小了路径搜索范围，提高了算法效率等等。

3.3.2.1.4 粒子群优化法

粒子群优化法起源于人们对鸟类觅食行为的探索，其流程框图如下图所示。

JCGC202205004_02200

图15 粒子群算法框图

每只鸟看作一个有速度和位置信息的粒子，每个粒子找到食物后将自己的路径信息与同类共享，通过与同类比较，选取更近的路径，多次比较迭代后，得到最优解。粒子群优化算法具有收敛速度快，鲁棒性强，精度高等优点，但也容易造成收敛过早，局部最优解的问题。

粒子群算法也存在一系列的优化算法，如李学军提出了反向学习粒子群的方法应用于机器人的多目标路径选择，该算法模型简单，计算速度较快；付兴武等将粒子群优化算法与天牛须算法结合，将每个粒子加入天牛会对环境进行自我判断的能力，使算法规划效率更高，路径更优；杨红果等将传统粒子群算法与遗传算法相结合，有效克服了传统粒子群算法易于陷入局部最优以及迭代次数多的缺点。

3.3.2.2 局部路径规划算法

局部路径规划属于动态规划，是指无人车辆通过传感器，实时感知环境信息，对局部环境建模，完成从当前节点到下一子节点路径的局部最优化。局部路径规划算法根据其特点可分为采样方法、条件约束法、机器学习法，以下将对滚动窗口算法、人工势场算法、强化学习算法分别进行概括。

3.3.2.2.1 滚动窗口算法

滚动窗口算法是指根据传感器感知环境，通过滚动的方式对路径作出在线规划，每滚动一步（按照上一步的规划路径），探测到新的环境信息，进而对上一步的规划作出反馈并用启发式方法优化下一步子目标的选择，并做出新的局部路径规划。如此循环达到对局部动态环境的实时路径规划效果。该算法计算量较小，对环境较为敏感，可有效避开障碍物，具有实时性。

3.3.2.2.2 人工势场算法

人工势场算法是指人为建立一个虚拟力场，车辆在环境中同时受到障碍物的斥力和目标点的吸引力，车辆受到的力的大小与其同障碍物或目标点的距离负相关，即距离越短，受力越大（如下图所示）。

JCGC202205004_03600

图16 人工势场示意图

在上图所示的人工势场中，无人车辆在合力作用下不断前往下一个目标点，进行运动。人工势场算法存在许多问题，例如在障碍物附近的目标点，其产生的合力几乎为零使得无人车难以到达，陷入局部最优；在经过狭窄路径时易产生左右震荡的问题等。因此人工势场算法不宜用于高自由度下的车辆路径规划问题。但是人工势场算法的简单结构，快速响应，规划路径平滑等特点依然吸引了众多研究学者的探索。

人工势场法的相关优化算法也有许多，例如陈麒杰等提出了改进的人工势场，在斥力函数中加入了和目标点与障碍物之间的距离相关的斥力影响因子，避免了无人机或无人车辆相撞；何乃峰等在斥力场函数中引入位姿阈值增益，利用退火算法原理，当无人车陷入局部最小值时，重构障碍斥力函数，以一定的概率达到全局最优解；李军等将传统斥力场更改为椭圆形使得路径更平滑，建立道路边界斥力场使得车辆不会偏离道路，对移动的障碍添加速度斥力场使得环境更符合实际情况等等。

3.3.2.2.3 基于强化学习的路径规划算法

强化学习是无人车辆通过传感器与环境进行信息交互试错学习，对无人车辆应对不同环境的行为作出奖惩评判，从而不断优化行动方案达到最佳。强化学习可较好地应对复杂动态环境，但其学习能力难以提升，面对复杂环境往往计算收敛速度慢，限制了其实时局部路径规划的实际表现。但强化学习算法需要一定时间的试错与长期的调试，在有限的时间及20分钟内的现场运行中难以实现，因此不适合本次任务的要求。

3.3.2.3 对比分析与总结

综合上述分析，可以发现全局路径规划普遍显示出求解效率较低，易于陷入局部最优的问题，但算法的求解能力与收敛速度是一对相互排斥的性质，因此全局规划的优化改进方法主要集中于在保证算法求解能力的同时提高求解效率，增大求解过程中解的多样性以保证最终解的优良性。上述全局路径规划算法的特点比较及改进方法如下图。

JCGC202205004_03000(2)

图17 全局路径规划算法的优缺点以及其改进方式

局部路径规划的对算法的反应速度要求较高，以至于算法的求解能力较弱或增强求解能力的途径较为困难。但是局部路径规划算法可看做一次次基于当前环境的全局路径规划，将全局路径规划算法同局部路径规划算法相结合，克服求解能力弱的缺点。上述局部路径规划算法的特点比较及改进方法如下图。

JCGC202205004_04400(3)

图18 局部路径规划算法的优缺点以及其改进方式

避障与路径算法多种多样，仍然有许多本文未列出的经典算法，如Bug法采用发现障碍后绕行的方法寻找路径（如下图），向量场直方图法（VFH）根据当前小车传感器数据对周围环境创建一个极坐标表示的局部地图，神经网络算法以小车当前的方向和速度、传感器的信号作为输入而以下一个目标或者运动方向作为输出，模糊逻辑法将操作经验转换为对应的模糊逻辑语句来控制小车的避障过程，栅格法将整个地图进行栅格划分从而将问题转化为图上起点栅格和终点栅格的最短路径问题，随机法通过在每次小车开到“尽头”时判断是否已经到达终点选择下一步停止或者随机转向等等，各种算法各有优劣，也有不同的应用场景。


图19 Bug1算法与Bug2算法示意图

    3.3.3 避障及路径规划算法设计注意点

首先，应注意传感器的适用条件。比如红外线会被黑色物体吸收，超声会被海绵吸收，以及红外和激光难以探测透明物体等等。其次，可以采用多种传感器结合互补的方式。理论上没有传感器可以适合于所有情况，因此不妨考虑多种传感方式结合互补，使得小车对环境的感知更加可靠。最后，应注意考虑自身其他配件的影响。比如多个同时工作的超声波传感器，很容易就影响到彼此，也会使超声感知的工作周期变长，因此多个超声传感器不能同时工作。

4. 原理设计方案

参考文献

[1] 何武剑,邱浩峰,曲晓坤,陈迦勒,孙俊巧,余腾龙.智能小车发展应用研究[J].河南科技,2022,41(11):26-29.DOI:10.19968/j.cnki.hnkj.1003-5168.2022. 11.005.

[2]张忠民、郑仁辉：《基于模糊PID的麦克纳姆轮移动平台的控制算法》，《应用科技》，2017年第06期。

[3]高至、李传昌、梁世伟、兰晔、李岳洪：《智能车路径识别及转向控制的研究与实现》，《南方农机》，2019年第12期。

[4]赵艳娥、张建武：《轮毂电机驱动电动汽车电子差速系统研究》，《系统仿真学报》，2008年总第18期。

[5]杨俊驹、林睿、王振华、孙立宁：《轮式移动机器人运动控制系统研究与设计》，《现代电子技术》，2016年第02期。

[6]许皓博.自动循迹跟随智能小车设计[J].数字通信世界,2022(01):132-134+137.

[7]洪一民,钱庆丰,章志飞.基于STM32的智能小车循迹避障测距的设计[J].物联网技术,2022,12(01):12-13+17.DOI:10.16667/j.issn.2095-1302.2022.01.004.

[8]王信乐,刘祚时.基于线性CCD的智能小车循迹系统设计与研究[J].制造业自动化,2020,42(08):79-84.

[9]余世干,张廉洁,张旭东,戎强强.基于线性CCD检测的寻线智能车设计与实现[J].赤峰学院学报(自然科学版),2015,31(19):65-67.DOI:10.13398/j.cnki.issn1673-260x.2015.19.025.

[10]毛祖光,杨洁.自循迹智能小车控制系统的设计与实现[J].科技风,2022(14):7-9+69.DOI:10.19392/j.cnki.1671-7341.202214003.

[11]冯谣.基于CCD摄像头智能循迹小车的研究与开发[J].浙江交通职业技术学院学报,2018,19(Z1):16-20.

[12]张迪.智能车中摄像头的图像畸变矫正[J].信息系统工程,2012(07):82-84.

[13]周阳,雷鹏.飞思卡尔智能车竞赛中赛道曲率的单点求法[J]. 中国电子商务, 2013(7):1.

[14]蒋旭,吴涛.两点算法求智能车赛道曲率[J].新技术新工艺,2014(04):32-33.

[15]刘得权,李政清,王榜,秦家屹,智慧超,张雪峰,颜微.智能小车环境感知系统的设计[J].山西电子技术,2022,(01):16-18.

[16]吴慧珍.智能车载避障算法研究[D].中国矿业大学,2021.DOI:10.27623/d.cnki.gzkyu.2021. 002921.

[17]程天明.机器人定位与避障的关键技术研究[D].广东工业大学,2021.DOI:10.27029/d.cnki. ggdgu.2021.002053.

[18]王涛,黎玉康,刘文学.无人车辆路径规划算法发展现状[J].舰船电子工程,2022,42(05): 15-22.

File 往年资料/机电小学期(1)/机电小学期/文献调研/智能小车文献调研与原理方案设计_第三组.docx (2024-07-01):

智能小车文献调研与原理方案设计

荆尹浩宇 滕一铭 张佳悦

2021年7月2日

目录

# 智能小车文献调研与原理方案设计

# 1. 引言

为完成《机电系统设计实践》课程的主要任务，将智能小车更好地予以实现，笔者将通过需求分析、任务分解、文献综述初步明确智能小车的要求及相应的需要细化的问题，了解目前的相关技术进展，并据此进行初步的原理方案设计。

智能小车是计算机、传感、通信、人工智能、自动控制等技术的集合，将环境感知、自动决策、自动驾驶等功能融为一体，是典型的现代高新技术结合体。近年来，智能小车在应用和技术上都取得了很大的进步，它也因可以搭载多种模块且具有强大的环境适应能力，被广泛地应用于各领域。

本文中所实现的智能小车指能够自主移动并实现在循迹场景与避障场景中自主完成抓取、运输和卸载货物工作的AGV轮式小车。在对智能小车任务进行需求分析与任务分解后，本文将从机械结构及运动控制、循迹传感器及算法、避障传感器及算法、控制器硬件、数据通讯、电机与驱动六部分进行文献调研并综述。之后，本文将通过需求分析与文献调研所得结果，进行初步原理方案的设计。

# 2. 需求分析与任务分解

课程的总体任务为“设计并实现一个机电系统，在2种不同场地，分别按规定路线自助寻线与无固定路线自助避障，将给定货物从一个指定位置运输到另一指定位置”，可将此任务分解为车架主体、抓取结构、任务所用传感器、控制器硬件、数据通讯、电机与驱动、总电源与二次电源七个方面进行逐个分析。

## 2.1 车架主体

车架整体尺寸：在自助避障任务中，障碍物间的间距不小于350mm，因此，小车的宽度应小于350mm并留出适量裕度。

车架选用材料：车架材料的选择需具有一定刚度以保证结构稳定性，同时也应注意适当减重，使小车尽量轻便以提高速度。

车架空间结构：由于小车的占地面积不能过大，且需要在车架上装配多种元器件和电子线路，可以考虑将小车做成二层或三层结构。在设计车架空间结构时，需要考虑车轮、车体、模块电路板及电机等的重力配平，以提高稳定性。

驱动与转弯方式：驱动方式上，可以选择使用两轮或三轮并采用两轮驱动，也可以选择使用四轮并采用四轮驱动或者后轮驱动，几种方式各有优劣，将在后文中进行分析比较。转弯方式上，可以采用普通轮并通过差速转向或者偏转前轮转向予以实现，也可以采用麦克纳姆轮通过4个轮子不同转速的相互配合来实现全向移动，其特点及优劣比较也将在后文中予以阐述。

## 2.2 抓取结构

机械爪及舵机：货物尺寸为直径30mm，高40mm，其重量为50g，因此抓取结构中的机械爪需与货物尺寸相匹配，且相应舵机需要有足够的力矩。

抓取结构大小与工作空间：因小车本身体积有限，因此抓取结构不应过大。除此之外，还需考虑抓取结构的工作空间，如不能遮挡摄像头视野等。

抓取结构性能：一方面，抓取结构应尽可能精简小巧，以此保证较小影响车架结构并提高抓取稳定性；另一方面，需要从设计机构的角度提升抓取稳定性，确保将货物装上小车。

## 2.3 任务所用传感器

任务所用传感器可能有红外传感器、超声传感器、线阵CCD传感器、OpenMV等，不同传感器的作用不同，将在下文进行具体介绍与分析。在考虑传感器作用及选择之外，还需考虑传感器器件如何在车架上进行装配，从而合理安排车体结构。

## 2.4 控制器硬件

常用的控制器包括STM32F407开发板、MSP430F149开发板、Cyclone IV FPGA开发板等，不同控制器的性能不同，可以从接口需求、计算能力、传感功能需求、可利用资源、可实现性等方面综合考量进行选择。

## 2.5 数据通讯

需要实现的通讯任务主要包括实时图像、指令数据、状态参数和舵机命令的传输，具体的通讯方式包括USB线、异步串口、CAN和以太网等有线通讯方式和蓝牙、Zigbee、WiFi等无线通讯方式。不同的通讯方式有其各自的特点及优缺点，具体选型需要依据传输数据量、数据传输延时、具体元器件特点、车载与PC端软件开发量、硬件接口等因素综合决策。

## 2.6 电机与驱动

可以选用的电机有多种类型，具体包括航模舵机、直流电机、永磁同步电机、音圈电机、步进电机、交流异步电机等，其中前两种电机在智能小车中应用较多，不同电机之间的性能比较将在后文予以介绍。

## 2.7 总电源与二次电源

由于单片机、电机、舵机等不同元器件的所需电压不同，需要进行相应的电源与二次电源的选择，具体选择将在原理方案设计部分予以确定。

# 3. 文献综述

## 3.1 机械结构及运动控制

### 3.1.1 运动方式

现有的可以运动方式主要有三种，即轮式、步行式与履带式，下文将分别综述二者的实现方式及特点。

      3.1.1.1 轮式运动

轮式移动的AGV小车可以分为三种：两轮差速移动AGV小车、带舵轮的四轮移动AGV小车和三轮移动AGV小车。两轮差速移动AGV小车具有节省空间、机动性好等特点，被广泛应用在各大企业的生产工厂内。三轮移动和四轮移动的AGV小车则能够以轮式移动为特征，与步行、爬行或是其他非轮式的移动机器人相比，更加快捷，工作效率也更高，同时还具有无人值守自动化搬运、承载重量大、结构简单、可控性强、安全性好等优点。与物料送中常用的堆垛机、单轨小车、传送带、传送链相比，AGV的活动区域不受场地、道路和空间的限制。因此，在自动化物流系统中，最能充分地体现其自动性和柔性，实现高效、经济、灵活的无人化生产。

对于四轮式AGV小车，又可以细分为前驱、后驱以及四驱。前驱或者后驱由于驱动电机数量少，能够增加内部空间，在空间的利用上有更多的余地，减轻小车重量，耗能低。但由于前后配重不均匀，另一侧的车轮在行进过程中容易失去抓地力，出现转向不足或者转向过度的问题，对于操控性有负面影响。四驱的AGV小车则前后配重相对均匀，同时由于四轮均能够获得动力，行进过程操控性更好，容错性更高，更为稳定，在路面状况较为复杂时也拥有更好的适应能力，但是会导致小车自重较大，行动的灵活性受到影响，耗能也更大。


图1 轮式小车

      3.1.1.2 步行式运动

步行式机器人分为单腿式、双腿式和多腿式等等类别。

首先，足式机器人的运动轨迹是一系列离散的足印，轮式和履带式机器人的则是一条条连续的辙迹。崎岖地形中往往含有岩石、泥土、沙子甚至峭壁和陡坡等障碍物，可以稳定支撑机器人的连续路径十分有限，这意味着轮式和履带式机器人在这种地形中已经不适用。而足式机器人运动时只需要离散的点接触地面，对这种地形的适应性较强。正因为如此，足式机器人对环境的破坏程度也较小。

第二，足式机器人的腿部具有多个自由度,使运动的灵活性大大增强。它可以通过调节腿的长度保持身体水平,也可以通过调节腿的伸展程度调整重心的位置，因此不易翻倒，稳定性更高。同时，机器人的身体可以平稳地运动而不必考虑地面的粗糙程度和腿的放置位置。当机器人需要携带科学仪器和工具工作时，可以通过首先将腿部固定，之后精确控制身体在三维空间运动的方式，达到对对象进行操作的目的。


图2 步行式机器人

      3.1.1.3 履带式运动

履带车对地面单位压力小，下陷小，附着能力强，行驶通过能力强。一般按行驶系结构可分为前桥（从动桥）装雪橇或车轮、后桥装履带的半履带式，前后桥都装履带的全履带式和可互换使用车轮、履带的车轮-履带式三种类型。

履带能够使受力面积加大，增大摩擦，抓地力变好，相对地面的压强减小，不容易造成陷轮，并且结构简单，结实耐用。而且履带板上有花纹，可以安装履刺，所以在雨、雪、冰或上坡等情况时能牢牢地抓住地面，不会滑转。履带适合在条件不好的环境下作业，例如雪地、山坡、草地等。但是在生产成本上，履带车要比轮式车高很多。


图3 履带式小车

### 3.1.2 转向方式

在目前设计的智能小车中，转向多采用普通轮并使用差速法实现，也可以通过全向轮（即麦克纳姆轮）实现。

      3.1.2.1 普通轮（差速法）

参考阿克曼（Ackerman）转向几何学原理，即在汽车转向时4个轮胎都近似围绕一个中心点旋转以保证汽车的行驶稳定性。把汽车的形心作为质心，并且忽略路面情况变化等的影响，可得出四轮驱动差速转向小车的运动学模型如下图所示。


图4 四轮驱动差速转向小车的运动学模型

α1和α2分别为前左轮和后左轮，前右轮和后右轮的转角；2L为左右轮距离；2K为前后轮轴距；v和ω分别为车子质心的线速度和角速度；V1，V2，V3，V4分别为各个轮中心的实际运动方向。由此可以求出各速度和转角的关系。


另外，若小车的主体为两轮结构，可以通过使两轮以相同大小速度向相反方向旋转来实现原地转向，在需要原地转向的情况下较为便捷。

      3.1.2.2 麦克纳姆轮

随着现代控制技术和计算机技术的发展，移动机器人在越来越多的领域开始发挥至关重要的作用。作为移动机器人的关键部件，移动平台可以保证机器人的移动性和稳定性，成为了机器人领域的研究重点。其中麦克纳姆轮移动平台因具有平面上3个自由度的移动能力而逐渐受到了更多的关注。然而麦克纳姆轮移动平台的轮子并不能够直接转向，它依靠4个轮子各自不同转速的相互配合来实现全向移动，因此每一个轮子的运动都对整体的运动方向和速度大小有着很大的贡献。

全向轮又被称作麦克纳姆轮，它与普通轮之间的主要区别就在于它的圆周上分布有若干数量的辊子，这些辊子的轴线与轮子的轴线呈一定的夹角（本文所采用的麦克纳姆轮的偏置角为45°），辊子的外廓线所形成的包络面和轮的原始圆周面重合，这样保证了辊子能与地面一直保持接触。这些辊子还可以自由转动，这使得轮子只受到地面对辊子轴向上的力，而地面对辊子的圆周力则变为了滚动摩擦，可以近似看为零。因此，轮子与地面的接触力不再是沿轮子的圆周方向，而是与它呈一定的夹角，所以这种轮子可以在一个方向上受到摩擦力的驱动，而在另一个方向上自由移动。由4个这样的轮子便可以组合出不同的受力情况，从而使移动平台可以实现平面上3个自由度的移动。通过对于单轮的运动学分析可以求得全向轮运动的雅各比矩阵，通过控制四个轮的转速来控制运动平台的平动与转动速度。

用R表示全向轮轴心到轮外廓圆周面的距离即轮的半径；Vi表示第i轮的速度；α表示辊子轴线与全向轮轴线夹角；ωi表示全向轮绕轮轴的转速；i=1、2、3、4，分别代表左前轮、右前轮、左后轮、右后轮。联立可得矩阵方程：

V_i =(R/4)[1, 1, 1tanα, -tanα, -tanα-1/(l_0), 1/(l_0), -1/(l_0) 1tanα1/(l_0)][ω_1 ω_2 ω_3 ω_4 ]

式中 l_0 =W+Lcosα ，其中W为移动平台宽度，L为其前后轮轴距；而α取45°，其正负号已被提出，不再区分正负。逆运动学方程为：

[ω_1 ω_2 ω_3 ω_4 ]=K[V_y V_x ω]=(1/R)[1, cotα, -l_0 1, -cotα, l_0 11, -cotαcotα, -l_0 l_0 ][V_y V_x ω]

### 3.1.3 机械臂末端执行器

机械臂的末端执行器可以采用机械手爪、磁力/真空吸盘、仿生多指灵巧手等结构，其原理及特点如下。

3.1.3.1 机械手爪

机械手爪通常采用气动、液动、电动和电磁来驱动手指的开合。气动手爪应用广泛，气 动手爪结构简单、成本低，容易维修，开合迅速，重量轻。但空气介质的可压缩性使爪钳位 置控制比较复杂，稳定性不足，可靠性存疑。液压驱动手爪成本较高。电动手爪的手指开合电动机控制与机器人控制可以共用一个系统，但是夹紧力比气动手爪、液压手爪小。电磁手爪控制信号简单，但是电磁夹紧力与爪钳行程有关，只用在开合距离小的场合。液压手爪抓取力大、提升过程可靠、控制精准、动作灵敏，但由于夹紧力大，对于被夹物品的材料刚性有一定的要求。


图5 机械手爪

3.1.3.2 磁力/真空吸盘

磁力吸盘有电磁吸盘和永磁吸盘两种。磁力吸盘的特点：体积小，自重轻，吸持力强， 可在水里使用。磁力吸盘广泛应用于钢铁、机械加工、模具、仓库等搬运吊装过程中对块状、 圆柱形导磁性钢铁材料工件的连接，可大大提高工件装卸、搬运的效率，是工厂、码头、仓 库、交通运输等行业最理想的吊装工具，但是对所抓取的物品有磁性的要求。

真空吸盘原理简单，操作相对容易，但前提是要保证所抓取物品表面足够平整光滑，此外还需要注意对于吸盘盘面的清洁与保护，防止污渍与腐蚀等等，对于后期维护保养的要求较高。


图6 磁力吸盘

3.1.3.3仿生多指灵巧手

简单的夹钳式取料手不能适应物体外形的变化，不能使物体表面承受比较均匀的夹持力，因此，无法满足对复杂形状、不同材质的物体实施夹持和操作。为了提高机器人手爪和手腕的操作能力、灵活性和快速反应能力，使机器人能像人手一样进行各种复杂的作业，如装配作业、维修作业、设备操作以及机器人模特的礼仪手势等，就必须有一个运动灵活、动作多样的灵巧手。

多关节柔性手能针对不同外形物体实施抓取，并使物体表面受力比较均匀，每个子指由多个关节串接而成。手指传动部分由牵引钢丝绳及摩擦滚轮组成，每个指由2根钢丝绳牵引，一侧为握紧，另一侧为放松。驱动源可采用电机驱动或液压、气动元件驱动。柔性手腕可抓取凹凸外形物体并使其受力较为均匀。柔性材料做成的柔性手一端固定，一端为自由的双管合一的柔性管状子爪。当一侧管内充入气体（液体），另一侧管抽出气体（液体）时，形成压力差，柔性手爪就向抽空侧弯曲。此种柔性手适用于抓取轻型、圆形物体，如玻璃器皿等。


图7 仿生多指灵巧手

## 3.2 循迹传感器及算法

### 3.2.1 红外传感器

红外发射管竖直发射出红外线，红外接收管接收反射的红外线，用光电传感器或灰度传感器可以将接收到的红外线光信号转化成电信号。若红外射线照在白色地面上，红外传感器接收到反射回的红外线比较强，转化的电信号也比较强；若红外线照在黑色引导线上，这时反射回的红外线的强度较弱，转化为的电信号也较弱。小车的循迹通过红外传感器接收到的信号强弱来控制，通过转化为的电信号强弱差异，就可以判断并调整小车的行驶路线。

查看源图像

图8 红外传感器（左） 五路红外循迹模块（右）

以五路红外循迹模块为例，其控制算法如下表所示：

表1 五路红外循迹模块控制算法示例表


控制流程大致如下：


图9 五路红外循迹控制流程

红外传感器具有灵敏度高、体积小、易于安装等优点，但由于在循迹模块中其数量通常较少，因此该方法对道路的前瞻性不强，循迹效率不高。

### 3.2.2 线阵CCD

图像信息采集时，单片机的端口与CCD的图像灰度信息输出引脚相连，线阵CCD是单行采集图像的，并且采集回来的数据是灰度值，对灰度值进行二值化和滤波处理后，最终可以确定跑道的路况。

滤波处理多采用时域滤波法，可以采取平均值滤波、中值滤波、限值滤波与滑动平均值滤波等算法，以对数据进行降噪处理。考虑到CCD图像的畸变视角的变化以及环境的影响，阈值的确定通常采用动态阈值法，可以通过取平均电压值、max与min的均值、大津算法等方法求得阈值。此外, 针对每行中的孤立噪点, 可以采用计数法排除。

在对图像进行上述处理后，可以通过跟踪引线的黑线提取算法来提取轨迹线。如果连续黑点数小于某个阈值时, 认为是噪声影响, 而非实际的黑线, 从而可以减少误判概率. 在完成轨迹线的提取后，通过计算可以得出当前小车的方向与黑色引导线之间的位置偏差，接着将此位置偏差信号输入到闭环位置控制系统，经过PID闭环位置控制算法进行调节，将调节后的信号再输入到驱动控制模块，实现对电机在速度上的控制，使小车沿黑色引导线行进。

线阵CCD的优点是路径分辨率高，前瞻性较强，可以更远更早地感知路径的变化，在小车本体跑偏之前修正行进方向，并且可以实时地监控路径的位置，及时纠偏。但此方法的图像获取时间较长，测量效率较低，并且图像精度可能会受扫描运动精度的影响。

### 3.2.3 摄像头

由于摄像头提供的图像信息较多、较复杂，因此在对图像信息进行处理时，首先要对图像进行有效部分提取, 提取出感兴趣区域后，对图像从左到右、从上到下进行隔行扫描，并读取扫描的每个像素点的灰度值，以此为依据进行分割从而提取出循迹小车所在的赛道信息。分割阈值的选择一般也采取动态阈值法，可以从最低灰度等级向高灰度等级进行遍历， 找到第一个灰度等级对应的像素概率为零的灰度级作为最后阈值。在获得赛道信息后，可以根据小车的具体偏移量利用PD控制算法来计算舵机的转角，再利用PID算法闭环调节小车的速度。

由于摄像头与地面之间存在俯角，导致采集到的图像并不是一个方形区域，而是一个近处区域小、远处区域大的梯形区域，图像会出现失真。


图10 梯形失真示意图

对于纵向畸变的矫正，通常采用非均匀行采集的算法，其坐标变换表达式为y=vd。其中d表示两行采样之间的间隔。对于横向畸变，矫正后坐标系之间的变换公式为

x=(CD)/(N-1)(u-N/2) ，式中CD表示视角的底部宽度，N表示总列数。


图11 非均匀行采样示意图

对于赛道曲率的计算有多种算法，最简单的一种方法是利用 q=|(x_3 -x_2 )-(x_2 -x_1 )| 来计算，式中 x_1 、 x_2 和 x_3 为3个实际距离相等的行的黑线位置。赛道曲率还可以用两点法和三点法计算，三点法计算的本质是求三角形的外接圆半径，但往往需要对图像的畸变进行矫正；对于两点法，如果智能车在赛道中心线上，则有 k=(2l_(BC))/(l_(AB)^2 +l_(BC)^2) ；如果小车不在赛道中心线上，则有


其中， A_1 为智能车的左偏移点, 偏距为 l_(AA1) , 曲率为 k_1 ； A_2 为智能车的右偏移点，偏距为 l_(AA2) , 曲率为 k_R 。


图12 小车在赛道中心线上（左） 小车不在赛道中心线上（右）

采用摄像头循迹可以获得二维的图像信息，在前瞻性和纠偏能力上比线阵CCD更优，不过由于其像元数总数多，但每行的像元数比线阵少，因此其图像分辨率比线阵CCD要低，不适用于要求视场大、图像分辨率高的情形。

## 3.3 避障传感器及算法

### 3.3.1 常见避障传感器

3.3.1.1 红外避障传感器

原理：红外避障主要是以红外测距传感器为主，红外测距都是采用三角测距的原理。红外发射器按照一定角度发射红外光束，遇到物体之后，光会反向回来。检测到反射光之后，通过结构上的几何三角关系，就可以计算出物体距离D。

适用范围：可通过电位器旋钮调节探测距离，有效距离范围0~20cm，顺时针调电位器，检测距离增加，逆时针调电位器，检测距离减少。红外避障传感器广泛应用于及机器人避障、避障小车、流水线计数及黑白线寻迹等众多场合。

优势：结构简明，便于装配，成本低廉，反应灵敏，便于近距离路面情况的检测，抗干扰能力强，不会因为周围环境的差别而产生不同的结果。

劣势：只能对路面情况做简单的黑白判别，检测距离和精度有限，传感器高度位置的差异可能会对其检测造成干扰。

3.3.1.2 超声波避障传感器

原理：超声波测距的原理比红外线更加简单，因为声波遇到障碍物会反射，而声波的速度已知，所以只需要知道发射到接收的时间差，即可轻松计算出测量距离，再结合发射器和接收器的距离，就能算出车体到障碍物的实际距离。

适用范围：作用距离一般在5-10m之间，但是会存在一个最小探测盲区，一般在几十毫米。由于需要主动发射声波，因此太远的障碍物会使精度随着声波的衰减而降低，不适合用超声波避障传感器。此外，对于海绵等吸收声波的物体或者在大风干扰的情况下，超声波将无法工作。超声波避障传感器是移动机器人、AGV、无人机、汽车避障中常用的传感器。

优势：结构简单，制造方便，成本较低；超声波对雨、雪、的穿透力强，可以在恶劣天气下工作；超声波对光照和色彩不敏感，可以用于识别透明以及反射性差的物体；不容易受环境电磁场的干扰。

劣势：测距速度不如激光测距和毫米波测距；超声波有一定的扩散角，只能测量距离，不可以测量方位，只能在低速时使用；发射信号和余振的信号都会对回波信号造成覆盖或者干扰，因此在低于某一距离后就会丧失探测功能。

3.3.1.3 激光雷达传感器

原理：激光雷达是将激光束发送到目标，通过接收和反射之间的时间间隔确定到目标的距离，通过几何变换激光束角度获得有关对象位置的信息。用激光雷达进行目标障碍物的检测主要有两种方法。一种是有前验模型的，在已有模型的基础上同时完成障碍物的检测和目标的分类；另一种是无先验模型的，在拟合分离地面信息后从剩余的非地面信息中进行障碍物的分类检测。激光雷达按照计算距离的方式可以分为三角测量和飞行时间测量(TOF)两种；按照探测范围可以分为单线激光雷达与多线激光雷达两种。

适用范围：车载激光雷达的探测距离为150m，三角测距原理的激光雷达只有几米，TOF法测距可达几百米。

优势：探测范围更广，探测精度更高，可以获取比较致密的点云信息，在对环境的感知及对障碍物的检测上有独特优势。

劣势：在雨雪雾霾天、沙尘暴等恶劣天气下不能正常工作，受环境影响大；无穿透能力，探头须完全外露才能达到探测效果，影响车辆外形美观。

3.3.1.4 毫米波雷达传感器

原理：毫米波雷达工作在毫米波段，通常毫米波是指30～300GHz频段(波长为1～10mm)。毫米波雷达传感器由振荡器 (https://www.elecfans.com/tags/振荡器/)产生一个频率随时间逐渐增加的信号，信号遇到障碍物之后反弹回来，其时延是距离与光速比值的二倍。返回波形与发出波形之间存在频率差，此频率差与时延呈线性关系：物体越远，返回的波收到的时间越晚，则其与入射波的频率差值越大。因此，可以通过检测差拍频率的高低判断传感器到障碍物的距离。

适用范围：毫米波雷达的探测距离较长,可以达到200多米。毫米波雷达广泛应用于导弹制导、目标监视和截获、炮火控制与跟踪和雷达测量等方面。

优势：距离远、可靠性高、不受光线、尘埃影响，测量距离比摄像头更长，价格相对激光较为便宜。

劣势：毫米波会在雨、雾和湿雪等高潮湿环境有所衰减；大功率器件和插损的影响会降低毫米波雷达的探测距离；树丛穿透能力差，相比微波，对密树丛穿透力低；元器件成本高，加工精度相对要求高，单片收发集成电路的开发相对迟缓。

### 3.3.2 避障及路径规划算法

3.3.2.1 全局路径规划算法

全局路径规划是在对环境整体布局完全已知的条件下的路径规划方法，意在找出满足某些条件的最优解。全局路径规划算法有很多，大致可分为传统算法、智能算法及二者相结合的混合算法，具体包括A*算法、遗传算法、蚁群算法、粒子群算法等。

3.3.2.1.1 A*算法

A*算法是在Dijkstra算法的基础上加入了启发函数和预估代价的一种启发式算法，广泛应用于静态环境下的最短路径直接搜索。其公式表示为f(n)=g(n)+h(n)，其中，f(n)是从初始点经由节点n到目标点的估价函数，g(n)是在状态空间中从初始节点到n节点的实际代价，h(n)是从n到目标节点最佳路径的估计代价。算法的关键在于估价函数f(n)的选取：设n到目标节点的距离实际值为d(n)，若h(n)≤d(n)，则搜索点数多，搜索范围大，效率低，但仍能得到最优解；若h(n)=d(n)，则搜索将严格沿着最短路径进行，此时的搜索效率是最高的；若h(n)＞d(n)，则搜索的点数少，搜索范围小，效率高，但不能保证得到最优解。

有越来越多的学者对A*算法进行了优化，如陈鑫鹏等提出了等步长分层拓展的方法；刘子豪等结合跳跃点搜索理论，优化了子节点的选择；李世国等采用了双向A*算法，从起始点和目标节点同时相向开始搜索直至重合；唐碧君等为解决传统A*算法使得无人车辆容易出现不必要的转向和与障碍物产生碰撞的问题，提出了改进混合A*算法；闵海涛等根据非结构化环境的特点，提出了全球导航层与局部规划层相结合的环境描述方法和基于非结构化环境中自动驾驶车辆A*算法的改进型局部运动规划算法。改进的算法中，通过设置安全空间避免了轮廓碰撞，在启发式功能设计中考虑了路径曲率的成本。与原始算法相比，它们提高了路径的平滑性，从而使路径更符合车辆运动特点。

3.3.2.1.2 遗传算法

遗传算法的基本思想脱胎于达尔文的进化论和孟德尔的遗传论，其流程框图下图所示。


图13 遗传算法框图与遗传算法的执行过程

假设一个初始解集，将每个解视为染色体不同的个体，将其置于一系列的约束条件之中，按照物竞天择，适者生存的原则，筛选出表现较为良好的个体，将其复制、交叉、变异产生新一代的个体集，通过一代代进化筛选，最终得到最适应约束条件的个体也就是最优解。但是此类算法在环境偏复杂时，结果收敛速度较慢，无法确定精确最优解，算法的参数难以定量等不足。但是它依然具有宽广的前景和很大的潜力，吸引了众多学者展开研究。

3.3.2.1.3 蚁群算法

蚁群算法于1992年被首次提出，其创始人意大利学者Dorigo等在蚂蚁觅食行为中得到灵感，如下图所示。


图14 蚁群迷失行为简图及蚁群系统示意图

蚂蚁在觅食的路径上会留下信息素，当找到食物，蚂蚁原路返回，该路径上的信息素浓度将明显高于其他没有找到食物的路径，后来的蚂蚁选择路径的概率随着信息素浓度的增高而增加，且信息素有挥发性，使得有食物的路径上信息素浓度与没有食物路径上的信息素浓度差距越来越大。而有食物的路径中，路程越短的路径单位时间内通过的蚂蚁越多，信息素浓度越高，导致最终蚂蚁的路径趋向于最近的食物路径。蚁群算法在全局优化方面效果良好，且鲁棒性强，但同时也有计算量大的缺陷，且由于信息素的累计容易导致局部最优解。

蚁群算法也存在多种优化算法，如王苏彧等将传统的定常数信息素挥发因子跟改为随时间变化的服从Laplace分布的信息素挥发因子，加强了算法路径的多样性，保证了结果的最优性；徐玉琼等提出变步长蚁群算法，将传统蚁群算法中的单步长扩展为除了有障碍存在以外的的全局环境选择跳点，该算法收敛速度较之传统算法大幅提高，且在复杂环境下也能有较好的表现；桑和成等提出了转角启发因子，令路径选择的有效性大大提高并引入估价函数思想，对下一节点与目标节点的距离进行评估，缩小了路径搜索范围，提高了算法效率等等。

3.3.2.1.4 粒子群优化法

粒子群优化法起源于人们对鸟类觅食行为的探索，其流程框图如下图所示。

JCGC202205004_02200

图15 粒子群算法框图

将每只鸟看作一个有速度和位置信息的粒子，每个粒子找到食物后将自己的路径信息与同类共享，通过与同类比较，选取更近的路径，多次比较迭代后，得到最优解。粒子群优化算法具有收敛速度快，鲁棒性强，精度高等优点，但也容易造成收敛过早，局部最优解的问题。

粒子群算法也存在一系列的优化算法，如李学军提出了反向学习粒子群的方法应用于机器人的多目标路径选择，该算法模型简单，计算速度较快；付兴武等将粒子群优化算法与天牛须算法结合，将每个粒子加入天牛会对环境进行自我判断的能力，使算法规划效率更高，路径更优；杨红果等将传统粒子群算法与遗传算法相结合，有效克服了传统粒子群算法易于陷入局部最优以及迭代次数多的缺点。

3.3.2.2 局部路径规划算法

局部路径规划属于动态规划，是指无人车辆通过传感器，实时感知环境信息，对局部环境建模，完成从当前节点到下一子节点路径的局部最优化。局部路径规划算法根据其特点可分为采样方法、条件约束法、机器学习法，以下将对滚动窗口算法、人工势场算法、强化学习算法分别进行概括。

3.3.2.2.1 滚动窗口算法

滚动窗口算法是指根据传感器感知环境，通过滚动的方式对路径作出在线规划，每滚动一步（按照上一步的规划路径），探测到新的环境信息，进而对上一步的规划作出反馈并用启发式方法优化下一步子目标的选择，并做出新的局部路径规划。如此循环达到对局部动态环境的实时路径规划效果。该算法计算量较小，对环境较为敏感，可有效避开障碍物，具有实时性。

3.3.2.2.2 人工势场算法

人工势场算法是指人为建立一个虚拟力场，车辆在环境中同时受到障碍物的斥力和目标点的吸引力，车辆受到的力的大小与其同障碍物或目标点的距离负相关，即距离越短，受力越大（如下图所示）。

图16 人工势场示意图

在上图所示的人工势场中，无人车辆在合力作用下不断前往下一个目标点，进行运动。人工势场算法存在许多问题，例如在障碍物附近的目标点，其产生的合力几乎为零使得无人车难以到达，陷入局部最优；在经过狭窄路径时易产生左右震荡的问题等。因此人工势场算法不宜用于高自由度下的车辆路径规划问题。但是人工势场算法的简单结构，快速响应，规划路径平滑等特点依然吸引了众多研究学者的探索。

人工势场法的相关优化算法也有许多，例如陈麒杰等提出了改进的人工势场，在斥力函数中加入了和目标点与障碍物之间的距离相关的斥力影响因子，避免了无人机或无人车辆相撞；何乃峰等在斥力场函数中引入位姿阈值增益，利用退火算法原理，当无人车陷入局部最小值时，重构障碍斥力函数，以一定的概率达到全局最优解；李军等将传统斥力场更改为椭圆形使得路径更平滑，建立道路边界斥力场使得车辆不会偏离道路，对移动的障碍添加速度斥力场使得环境更符合实际情况等等。

3.3.2.2.3 基于强化学习的路径规划算法

强化学习是无人车辆通过传感器与环境进行信息交互试错学习，对无人车辆应对不同环境的行为作出奖惩评判，从而不断优化行动方案达到最佳。强化学习可较好地应对复杂动态环境，但其学习能力难以提升，面对复杂环境往往计算收敛速度慢，限制了其实时局部路径规划的实际表现。但强化学习算法需要一定时间的试错与长期的调试，在有限的时间及20分钟内的现场运行中难以实现，因此不适合本次任务的要求。

3.3.2.3 对比分析与总结

综合上述分析，可以发现全局路径规划普遍显示出求解效率较低，易于陷入局部最优的问题，但算法的求解能力与收敛速度是一对相互排斥的性质，因此全局规划的优化改进方法主要集中于在保证算法求解能力的同时提高求解效率，增大求解过程中解的多样性以保证最终解的优良性。上述全局路径规划算法的特点比较及改进方法如下图。

JCGC202205004_03000(2)

图17 全局路径规划算法的优缺点以及其改进方式

局部路径规划的对算法的反应速度要求较高，以至于算法的求解能力较弱或增强求解能力的途径较为困难。但是局部路径规划算法可看做一次次基于当前环境的全局路径规划，将全局路径规划算法同局部路径规划算法相结合，克服求解能力弱的缺点。上述局部路径规划算法的特点比较及改进方法如下图。

JCGC202205004_04400(3)

图18 局部路径规划算法的优缺点以及其改进方式

避障与路径算法多种多样，仍然有许多本文未列出的经典算法，如Bug法采用发现障碍后绕行的方法寻找路径（如下图），向量场直方图法（VFH）根据当前小车传感器数据对周围环境创建一个极坐标表示的局部地图，神经网络算法以小车当前的方向和速度、传感器的信号作为输入而以下一个目标或者运动方向作为输出，模糊逻辑法将操作经验转换为对应的模糊逻辑语句来控制小车的避障过程，栅格法将整个地图进行栅格划分从而将问题转化为图上起点栅格和终点栅格的最短路径问题，随机法通过在每次小车开到“尽头”时判断是否已经到达终点选择下一步停止或者随机转向等等，各种算法各有优劣，也有不同的应用场景。


图19 Bug1算法与Bug2算法示意图

### 3.3.3 避障及路径规划算法设计注意点

首先，应注意传感器的适用条件。比如红外线会被黑色物体吸收，超声会被海绵吸收，以及红外和激光难以探测透明物体等等。其次，可以采用多种传感器结合互补的方式。理论上没有传感器可以适合于所有情况，因此不妨考虑多种传感方式结合互补，使得小车对环境的感知更加可靠。最后，应注意考虑自身其他配件的影响。比如多个同时工作的超声波传感器，很容易就影响到彼此，需要谨慎考虑。

## 3.4 控制器硬件

可以选用的控制器硬件主要分为CPU、FPGA等。其中CPU的编程调试较为方便，主要通过串行执行，具体包括MCS-51系列、MSP430系列等单片机，STM32、LM3S8962等ARM架构与TMS320F2812等DSP。而FPGA的并发速度快，可靠性好，调试较为困难，具体包括Altera、Xilinx等。除此之外，也有一些其他的控制硬件，性能相对较差且调节较为困难，在此不再赘述。

## 3.5 数据通讯

在数据通讯方面，因小车需要远程无线通信控制，主要可考虑蓝牙、Zigbee、WiFi等方式。

3.5.1 蓝牙

蓝牙模块体积很小、便于集成，功耗低，具有很好的抗干扰能力，在短距离传输场景下较为可靠，蓝牙透传的通信速率较低。可以选用的HC-05模块具备全双工模式，可以实现在发送运行数据的同时接受来自手机的控制信号。

3.5.2 Zigbee

Zigbee是近年来才兴起的一种无线网络通信技术标准，拥有低功耗、低成本、短时延、安全性高等等优点，支持多节点之间的通信，但是传输速率较低。

3.5.3 WiFi

WiFi与蓝牙技术一样同属于短距离无线技术，拥有覆盖范围广，无需布线，传输速度快的优势，在当前的移动终端的联网方面应用广泛，但透传的WiFi串口协议速率容量相对较低。

## 3.6 电机与驱动

### 3.6.1 电机

在电机选用上，常用的电机包括航模舵机、直流电机、永磁同步电机、音圈电机、步进电机、交流异步电机等，其中前两种在智能小车上较常用。具体而言，航模电机可以进行较高精度的角度控制，实现自闭环控制，应用较为简单；直流电机适合连续旋转，可以通过电流驱动器与控制器实现角度与速度控制，较复杂；永磁同步电机适合长行程精密运动系统的直接出力；音圈电机适合微行程精密运动系统；步进电机适合开环的较高精度控制；交流异步电机需要通过变频驱动器进行速度控制，在力矩较大时往往与减速器共同使用，在智能车中应用较多。

### 3.6.2 驱动方式

在驱动方式上，常用驱动方式包括单驱动、两轮驱动与四轮驱动，而两轮驱动又分为前轮驱动、后轮驱动，四轮驱动又分为全时四驱、分时四驱与适时四驱。

单驱动方式一般有一个驱动兼转向轮和两个分布在车体轴线两边的固定从动轮。它对地表面要求一般，适用于广泛的环境和场合。

前轮驱动汽车是指发动机的动力直接传递给前轮从而带动车辆前进的驱动方式。前轮驱动的机械组件少而且集中，可以减轻重量，降低造价；由于动力直接传动，不需要传动轴，减少了损耗，运转效率更高，空间的利用上也有更多的余地。

后轮驱动汽车是指发动机的动力通过传动轴传递给后轮，从而推动车辆前进的驱动形式。后轮驱动的操控性好，后轮负责驱动，简化了操纵机构的布局和转向机构的结构，令前轮可专注于转向工作，因此转向时的车辆反应更加敏捷，重心靠后也让后驱车在行驶过程中可以更好的控制车身姿态任意变化。

全时四驱不需要驾驶人选择操作，前后车轮永远维持四轮驱动模式，行驶时将发动机输出扭矩按50:50设定在前后轮上，使前后排车轮保持等量的扭矩。全时四驱是公路过弯极限最高的传动方式，它可以实现车辆高速过弯时每个车轮分配到最佳的驱动力和追求过弯极限。

分时驱动是指驾驶者可以在两驱和四驱之间手动选择的四轮驱动系统，由驾驶员根据路面情况，通过接通或断开分动器来变化两轮驱动或四轮驱动模式。分时四驱技术很成熟，结构也比较简单，灵活性和可靠性好，加上其不用装配中央差速锁，成本要比全时四驱低得多。

适时四驱的车辆可以通过电脑来控制选择适合当下情况的驱动模式。适时四驱的结构比全时四驱简单得多，不仅可以有效降低成本，还有利于降低整车重量。由于可以有效避免特殊情况下后轮抓地力不足的弊端，适时四驱适合于前横置发动机前驱平台的车型配备。

# 4. 原理设计方案

在进行需求分析、任务分解与文献调研后，我们将初步设计方案整理如下：

## 4.1 车架总体

车架总体设计上，依据老师提出的初步方案存在的问题，我们将对应方案进行了优化：首先，对于四轮小车车轮难以共地会造成轻微颠簸的问题，由于小车机构的限制我们难以做出悬挂机构保证四轮小车车轮均保持接触地面，我们将原来的四轮小车改为三轮，保证了行驶过程中的稳定性；其次，对于OpenMV等传感器与小车旋转中心距离较远会造成小车提前作出响应的问题，我们调整布局后将OpenMV传感器均与小车前轮旋转中心的竖直位置重合，保证了小车传感与运动的协调一致；最后，对于OpenMV与遥控用摄像头的观察范围可能被机械臂遮挡的问题，我们增添了第三层结构放置OpenMV与遥控用摄像头，保证了小车视觉传感范围不被遮挡。具体的初步方案如下：

在运动方式上，考虑到本次实验场地地形较为平坦，我们计划选用轮式移动这一性价比较高的方案。在车架布局上，我们计划使用两个普通车轮与一个万向轮，分别置于小车的前端左右两侧和后端（3D模型如图20）。同时，由于小车尺寸的限制和需要装载多种元器件及电子线路的要求，我们计划将小车总体分为三层，第一层主要放置机械臂基座、电源电池组、电机及其驱动模块、超声波传感器等，第二层放置单片机、电压转换模块、IMU、蓝牙模块和WiFi模块等，第三层放置遥控用摄像头及OpenMV。经过调研分析后，我们对基本模块功能的构思如图21所示。


图20 小车3D模型图

41ac4e94692da26a1dd68c828df5e55

图21 基本模块功能构思

## 4.2 抓取结构

抓取装置的“钳爪”需要和货物尺寸匹配，同时要考虑抓取时的姿态，保证足够的压力与摩擦力，避免抓取过程中掉落。考虑到取物前后图像识别的需要，以及超声波传感器的位置，需要使抓取结构尽量短小，且抓取后不能遮挡摄像头与传感器。因此，综合考虑机械手爪、吸盘与仿生机械手三种抓取结构后，我们计划选用最简单的二自由度机械臂，用两台舵机控制手爪开合与机械臂角度完成抓取。具体而言，机械臂的转动轴与小车横向平行，抓取货物时在小车前方，将货物装上小车后将旋转至小车结构中，避免了对于摄像头收集图像信息的干扰。在具体的结构设计上，对于手爪的每个爪体用两个转轴连接，实现转动完成抓取。上部的轴一端固定，一端与手爪连接，下部轴一端与手爪连接，一边为齿轮，两侧由一个舵机驱动，通过齿轮传动同时驱动两个手爪。

ba6dff14cc585bb557a1a2cca4b749c

图22 机械手爪结构设计

## 4.3 任务所用传感器

在任务1（循迹部分）中，综合考虑红外传感器、线阵CCD、摄像头三种传感器后，我们计划选用OpenMV摄像头实现循迹功能。这是因为摄像头相比于红外传感器具有更强的前瞻能力，相比于线阵CCD具有更强的纠偏能力和较短的图像获取时间，且循迹过程中不需要较大的视场，因此选用摄像头作为寻线过程的传感器更合适。另外，了解到OpenMV具有更多的资源与更强大的功能，我们计划选用OpenMV以增强可实现性。

在任务2（避障任务）中，综合考虑红外、超声波、激光雷达、毫米波雷达、摄像头五种避障传感器后，我们计划选用OpenMV作为传感器，用IMU确定初始位姿，并用超声波传感器作为辅助。如此可以充分利用OpenMV获得的二维图像信息与较好的前瞻性，并用超声波测量小车其他方向距障碍物的距离作为补充。在实现方式上，我们初步打算利用IMU确定初始位姿后规定初始方向并在相应模型中建立对应的引力，通过随机算法与人工势场法的加权实现小车前进方向的实时更新，之后会在实现中具体论证可行性。若利用OpenMV进行避障任务遇到较大阻碍，也可选用四个超声传感器（前方左、中、右各放置一个固定传感器，后方中央放置一个旋转传感器）完成避障功能。

## 4.4 控制器硬件

硬件的选择主要基于计算能力和编程难易程度，具体而言，FPGA的并发速度快，可靠性好，但调试困难，其他传统形式则难度更大，相比之下，采用CPU会简便许多。在智能小车的循迹、避障任务中，显然对于计算力和内存要求最高的是图像处理。STM32具有一定的图像处理能力，但在这一领域树莓派的计算能力更好且同时支持OpenCV库，即可采用一些现有的函数对于采集的图像进行处理，但树莓派的开发环境搭建更为繁琐，STM32更适于硬件开发。考虑到OpenMV作为传感器则可以替代树莓派进行图像处理相关的工作，我们初步决定开发时以STM32为主，辅助OpenMV图像处理模块作为上位机。

## 4.5 数据通讯

考虑到小车需要进行远程无限通信与控制，因此需要寻找无线通讯的手段。在比较蓝牙、Zigbee、WiFi三种无线通讯方式后，我们计划选用更加熟悉的HC-05蓝牙串口模块作为单片机与移动终端的通讯方式，完成指令数据传输、状态参数传输、舵机命令传输的任务。而对于摄像头向PC机实时传输图像进行遥控，蓝牙和Zigbee的传输速率不足，需要使用WiFi模块进行传输。

## 4.6 电机与驱动

在电机选型上，由于控制车轮转动对于转动角度的控制精度要求很低，但对于电机功率与扭矩的要求较高，因此直流电机适合连续旋转、控制逻辑简单的特点符合我们的要求。在机械臂以及相机角度的控制上对于精度要求高，但对速度要求不高，且有小体积的需求，因此航模舵机更加合适。

在驱动方式上，由于四驱操作变量过多，且可能出现打滑等现象，因此为增强运动过程的可控性与稳定性，因此我们计划选用操控性更好的两驱结构。具体实现方式上，可以通过两个普通轮的差速转向实现循迹过程中小车的转向，通过原地转向实现避障过程中小车方向的改变，另外通过一个万向轮配合起到使小车平稳移动的作用。在车轮驱动上，我们计划选择L298N电机驱动模块，每个可以驱动两个电机，因此用一个驱动模块完成车轮驱动。

## 4.7 总电源与二次电源

表2 各元器件所需电压

元器件 | 所需电压
25GA370直流电机 | 12V
STM32F103单片机 | 5V
HC-05蓝牙串口模块 | 5V
L298N电机驱动模块 | 5V
OpenMV图像处理模块 | 5V
HC-SR04超声波传感器 | 5V
SG90舵机 | 5V
MG995舵机 | 5V
JY901S九轴IMU | 3.3V

经过调研后，我们将需要用到的各元器件所需电压整理如上表。由于需求主要为直流电源，而直流电机25GA370的额定工作电压为12V，因此我们选取实验室提供的由干电池串联而成的12V直流电源作为总电源，考虑到其他各个元件与模块的用电需求，还需要加入二次电源，即12V转3.3V和12V转5V的二次电源模块，即可满足电源电压的要求。

参考文献

[1] 何武剑,邱浩峰,曲晓坤,陈迦勒,孙俊巧,余腾龙.智能小车发展应用研究[J].河南科技,2022,41(11):26-29.DOI:10.19968/j.cnki.hnkj.1003-5168.2022. 11.005.

[2]张忠民、郑仁辉：《基于模糊PID的麦克纳姆轮移动平台的控制算法》，《应用科技》，2017年第06期。

[3]高至、李传昌、梁世伟、兰晔、李岳洪：《智能车路径识别及转向控制的研究与实现》，《南方农机》，2019年第12期。

[4]赵艳娥、张建武：《轮毂电机驱动电动汽车电子差速系统研究》，《系统仿真学报》，2008年总第18期。

[5]杨俊驹、林睿、王振华、孙立宁：《轮式移动机器人运动控制系统研究与设计》，《现代电子技术》，2016年第02期。

[6]许皓博.自动循迹跟随智能小车设计[J].数字通信世界,2022(01):132-134+137.

[7]洪一民,钱庆丰,章志飞.基于STM32的智能小车循迹避障测距的设计[J].物联网技术,2022,12(01):12-13+17.DOI:10.16667/j.issn.2095-1302.2022.01.004.

[8]王信乐,刘祚时.基于线性CCD的智能小车循迹系统设计与研究[J].制造业自动化,2020,42(08):79-84.

[9]余世干,张廉洁,张旭东,戎强强.基于线性CCD检测的寻线智能车设计与实现[J].赤峰学院学报(自然科学版),2015,31(19):65-67.DOI:10.13398/j.cnki.issn1673-260x.2015.19.025.

[10]毛祖光,杨洁.自循迹智能小车控制系统的设计与实现[J].科技风,2022(14):7-9+69.DOI:10.19392/j.cnki.1671-7341.202214003.

[11]冯谣.基于CCD摄像头智能循迹小车的研究与开发[J].浙江交通职业技术学院学报,2018,19(Z1):16-20.

[12]张迪.智能车中摄像头的图像畸变矫正[J].信息系统工程,2012(07):82-84.

[13]周阳,雷鹏.飞思卡尔智能车竞赛中赛道曲率的单点求法[J]. 中国电子商务, 2013(7):1.

[14]蒋旭,吴涛.两点算法求智能车赛道曲率[J].新技术新工艺,2014(04):32-33.

[15]刘得权,李政清,王榜,秦家屹,智慧超,张雪峰,颜微.智能小车环境感知系统的设计[J].山西电子技术,2022,(01):16-18.

[16]吴慧珍.智能车载避障算法研究[D].中国矿业大学,2021.DOI:10.27623/d.cnki.gzkyu.2021. 002921.

[17]程天明.机器人定位与避障的关键技术研究[D].广东工业大学,2021.DOI:10.27029/d.cnki. ggdgu.2021.002053.

[18]王涛,黎玉康,刘文学.无人车辆路径规划算法发展现状[J].舰船电子工程,2022,42(05): 15-22.

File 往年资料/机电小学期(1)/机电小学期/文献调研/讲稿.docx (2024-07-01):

首先进入车体结构的环节，这里分为车架总体和抓取机构两部分。

在车架总体上，相信大家对于我们的场地尺寸要求已经很熟悉了，我们的车身尺寸也要控制在较小的合理范围内，方便避障。因此如果需要在车架上装配多种元器件和电子线路，可以考虑将小车做成二层或三层结构。我们初步设计的车架方案如图，总体分为三层，底层主要放置包括机械臂基座、电源电池组、电机及其驱动模块、超声波传感器，中间层放置遥控用的摄像头、单片机、电压转换模块、蓝牙模块等等，最上层面积较小，仅放置前置的图像识别摄像头和WiFi模块。对于车体行进方式的设计，从图中也能看到我们选择了轮式小车的方式。机器人的移动通常分为三类。轮式小车拥有节省空间、机动性好、承载重量大、结构简单、可控性强、安全性好，缺点是对地形适应能力弱。步行式机器人有对地形适应性较强，对环境的破坏程度较小，运动的灵活性强，运动控制较为精确等优点，但缺陷在于研发成本高。履带式小车则拥有对地面单位压力小，行驶通过能力强，结构简单，结实耐用的优点，但是较为笨重，耗能高。综合以上优缺点，考虑到我们本次实验场地地形较为平坦，因此轮式小车是性价比最高的途径。

下面讲讲抓取结构。抓取装置的“钳爪”需要和货物尺寸匹配，同时要考虑抓取时的姿态，保证足够的压力与摩擦力，避免抓取过程中掉落。考虑到取物前后图像识别的需要，以及超声波传感器的位置，需要使抓取结构尽量短小，且抓取后不能遮挡摄像头与传感器。传统的主流抓取结构有三种。机械手爪中，气动手爪结构简单，轻量化，但可靠性欠缺；液压手爪抓取力大，精确性高，成本高；电动手爪易于控制，但夹紧力较小。吸盘有两种，磁力吸盘体积小，自重轻，实用场景广泛，但要求抓取的物品有磁性。真空吸盘原理简单，操作相对容易，但要求物体表面平整，对于维护保养的要求较高。仿生机械手则更是重量级，操作能力、灵活性和快速反应能力非常强大，能够进行复杂的抓取作业，但成本也随之大大增加。考虑到我们的低成本、易控制的需求，而抓取的物品没有磁性且重量较轻，电动手爪是最为合适的选择。在手爪结构的设计中，要考虑到舵机的安排与取物的放置等等问题，我们最终决定采用最简单的二自由度机械臂，用两台舵机控制手爪开合与机械臂角度完成抓取。

下面进入驱动控制的环节。这部分有四块内容。

首先是驱动方式。从我们选择的轮式小车考虑，鉴于四轮式小车在稳定性与操控性上的优势，我们选择四轮结构。此时的两种驱动方式的优缺点在PPT上写得很清楚了，虽然四驱看起来更加笨重，但是考虑到我们本次设计首先是要保证能够完成任务，需要在控制时有更大的发挥空间，因此选择操控性更好的四驱结构。

在转向上，我们在PPT上的两种方法间选择了后者。第一种差速法是智能小车转向中最常见的方法，车转向时4个轮胎都近似围绕一个中心点旋转以保证小车的行驶稳定性，通过控制内测轮与外侧轮的不同速度来实现不同的曲率半径，从而实现转向。而麦克纳姆轮是近几年非常火的一种智能小车运动方式，麦克纳姆轮移动平台具有平面上3个自由度的移动能力。它依靠4个轮子各自转速的配合来实现全向移动。与轮子的轴线呈45度的辊子自由转动，这使得轮子只受到地面对辊子轴向上的力。通过不同受力情况的组合，得到三个自由度的不同速度。因此依靠麦轮可以自由地控制小车的运动速度、方向与姿态，控制灵活性大大提高，在巡线任务中可能算法比较复杂，但在避障任务中可以大大简化车身姿态调整的算法，因此深得我们组的认可。在车轮驱动上，我们选择L298N电机驱动模块，每个可以驱动两个电机，因此用两个驱动模块完成车轮驱动。

硬件的选择主要基于计算能力和编程难易程度，可基于前期调研进行初步的选择。根据老师上课所说的，FPGA的并发速度快，可靠性好，但调试困难，其他传统形式则难度更大，相比之下，采用CPU会简便得多。在智能小车的循迹、避障任务中，显然对于计算力和内存要求最高的是图像处理。STM32具有一定的图像处理能力，但在这一领域树莓派的计算能力更好，同时支持openCV库，这意味着可以采用一些现有的函数对于采集的图像进行处理，但树莓派的开发环境搭建更为繁琐，STM32更适于硬件开发。openMV作为传感器则可以替代树莓派进行图像处理相关的工作。综合上述考虑，我们小组初步决定开发时以STM32为主，辅助openMV图像处理模块。

在数据通讯方面，考虑到小车需要进行远程无限通信与控制，因此需要寻找无线通讯的手段。我们调研了老师上课讲授的三种无线通讯手段，其优缺点相信大家都已经很熟悉了，这里不做过多的赘述了。考虑到蓝牙和Zigbee在使用上的相似性，我们选择了更加熟悉的HC-05蓝牙串口模块作为单片机与移动终端的通讯方式，完成指令数据传输，状态参数传输，舵机命令传输的任务。而对于摄像头向PC机实时传输图像进行遥控，蓝牙和Zigbee的传输速率不足，需要使用WiFi模块进行传输。

下面进入最后的电机电源部分。

在驱动电机的选型方面可以选用的电机有多种类型，具体包括航模舵机、直流电机、永磁同步电机、音圈电机、步进电机、交流异步电机等，其中前两种电机在智能小车中应用较多。由于控制车轮转动对于转动角度的控制精度要求很低，但对于电机功率与扭矩的要求较高，因此直流电机适合连续旋转、控制逻辑简单的特点符合我们的要求，在机械臂以及相机角度的控制上对于精度要求高，但对速度要求不高，且有小体积的需求，航模舵机更加合适。
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

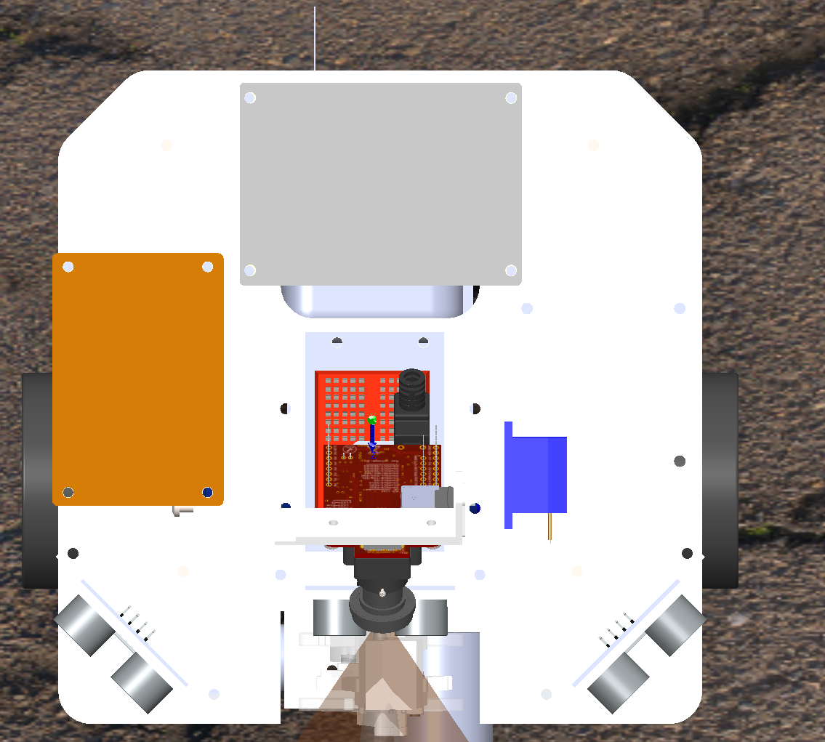
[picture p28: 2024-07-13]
MechaDesign/3D Models/重心位置示意图.png

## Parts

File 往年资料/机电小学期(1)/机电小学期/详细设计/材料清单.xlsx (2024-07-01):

材料 |  | 采购网址
控制平台 | 树莓派4代B （+外壳，散热片，电源线，风扇，16G储存卡）
 | STM32F103VET6开发板 | https://detail.tmall.com/item.htm?spm=a230r.1.14.64.71247093qWLax0&id=553122064820&ns=1&abbucket=12
传感器 | openMV | https://item.taobao.com/item.htm?id=612497720394&ns=1&abbucket=18
 | 激光雷达 | http://www.alsrobot.com.cn/goods-640.html
 | JY901S九轴IMU磁场加速度陀螺仪大气压强模块 | https://detail.tmall.com/item.htm?id=598203013266&ns=1&abbucket=0&skuId=4169997421172
 | 线性CCD(90度镜头) | https://item.taobao.com/item.htm?id=20749708544&ns=1&abbucket=12 (https://item.taobao.com/item.htm?spm=a230r.1.14.8.614e28fbKapafQ&id=20749708544&ns=1&abbucket=12)
 | HC-05蓝牙模块 | https://detail.tmall.com/item.htm?id=41327338424&rn=f2da8ad3bbef5681af64506ce8cc4ab0&abbucket=9
 | HC-SR04超声模块 | https://detail.tmall.com/item.htm?id=14466195609&ns=1&abbucket=12&skuId=3108214440220
执行器 | MG995 55G金属铜齿轮舵机 | https://item.taobao.com/item.htm?spm=a1z09.2.0.0.hFiM7A&id=530499783252&_u=bk64iil2e64
 | SG90 9G180度舵机 | https://item.taobao.com/item.htm?spm=a1z09.2.0.0.hFiM7A&id=528726113590&_u=bk64iil42c8
 | 直流减速电机带编码器1（12V，280rpm） | https://item.taobao.com/item.htm?id=533000737918&ns=1&abbucket=20 (https://item.taobao.com/item.htm?spm=a230r.1.14.13.466651825vUDDT&id=533000737918&ns=1&abbucket=20)
 | 直流减速电机带编码器2(12V,1:19减速比) | https://item.taobao.com/item.htm?spm=2013.1.w4004-10302371007.16.429c39e911jBcm&id=559699663497
 | L298N电机驱动板模块 | https://detail.tmall.com/item.htm?id=41248562401&ns=1&abbucket=12&skuId=4114388729372
 | ST-Link-V2 | https://detail.tmall.com/item.htm?id=521735720322&rn=fb11b15e9c6066752406e3460974b152&abbucket=9
 | USB转串口 | https://detail.tmall.com/item.htm?id=20601680359&spm=a1z09.2.0.0.UfbUKk&_u=bk64iilb651
 | 软串线 | 配套
车体 | 车轮+支架+联轴器 | 配套直流电机
电池 | 电池组 | 中发采购
 | 电源模块 | https://item.taobao.com/item.htm?_u=42fomaq693ee&id=16606969730

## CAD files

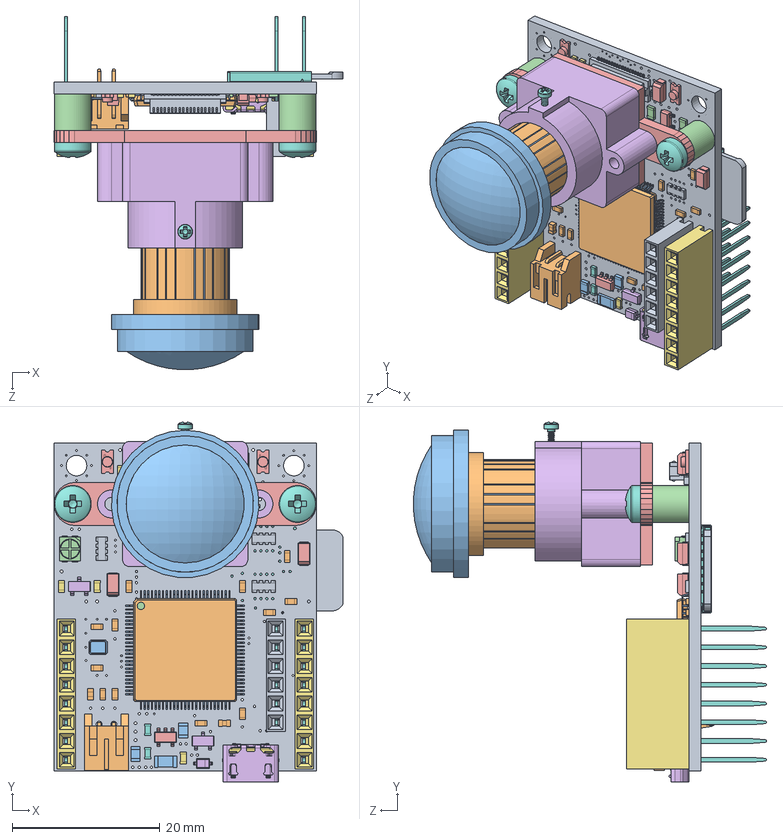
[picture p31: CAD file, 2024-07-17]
MechaDesign/3D Models/OpenMV H7.SLDASM
39.2 x 48.8 x 47.9 mm
base
C0603K_C0603K x 13
C0805K_C0805K x 2
cap3216h160 x 3
SOD323_BAT54HT1G
960240-6202-AR Body8 x 2
960240-6202-AR Pin Long x 22
960240-6202-AR Body6
Capacitor 0603 x 2
LED SMD RGB
LED 1206 IR x 2
SOT 23 x 2
Resistor 0603 x 5
R0603_SJR x 2
EXBV8V x 3
User Library-LQFP100-3_case
User Library-LQFP100-3_pin x 100
User Library-LQFP100-3_circle
SOT 23-5 x 2
UJ2-MIBH2-4-SMT_01
UJ2-MIBH2-4-SMT_02
1040310811_USD1040310811
DF12-36DS-0.5V
S2B-PH-K-S(LF)(SN)
Crystal-SM2520-4
Standoff metal 5x2.5mm x 2
ov7725
mount_lens
CSP2-28
pan head cross recess screw_iso x 3
microsd card
LENS_Standard
LENS_Wide

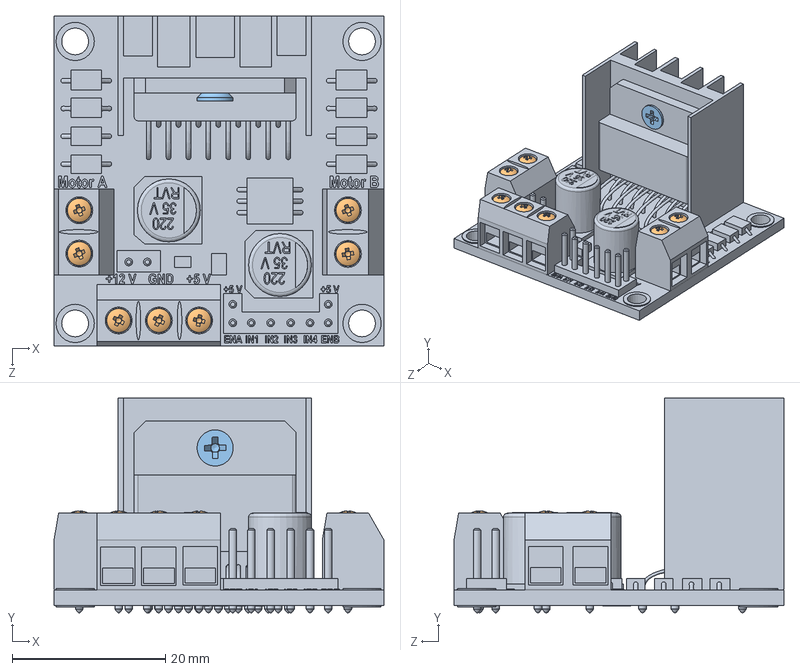
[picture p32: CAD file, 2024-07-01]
往年资料/机电小学期(1)/机电小学期/往年资料/宁梓豪组/小车模型/L298N/L298N.SLDASM
43.0 x 28.0 x 43.0 mm
L298N Stepper Motor Driver (Red)
pan head cross recess screw_iso x 7
countersunk flat head cross recess screw_iso

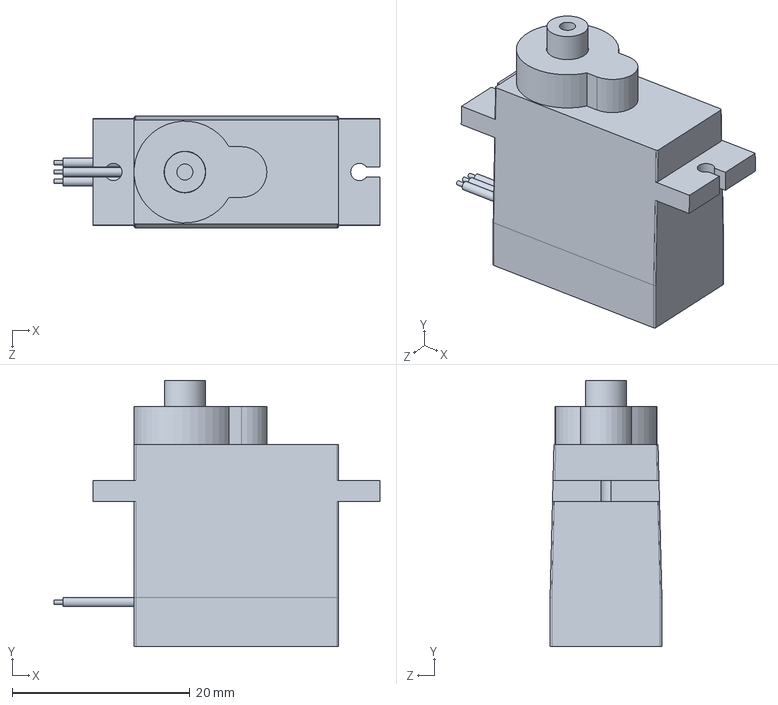
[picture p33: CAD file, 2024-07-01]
往年资料/机电小学期(1)/机电小学期/结题/智能小车3D模型/SG90/SG90.SLDASM
36.7 x 30.0 x 12.6 mm

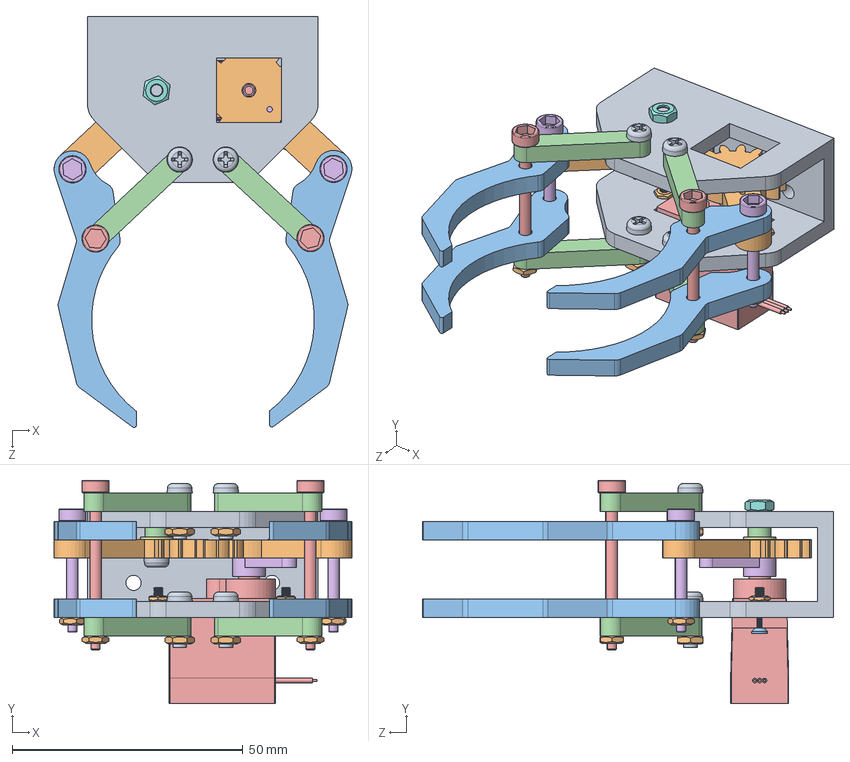
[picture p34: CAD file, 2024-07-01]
往年资料/机电小学期(1)/机电小学期/结题/智能小车3D模型/机械臂/机械臂.SLDASM
64.6 x 48.4 x 89.0 mm
支撑板（改）
齿轮传动杆 x 2
机械手爪（改） x 4
连杆（改） x 4
Tower Pro 9g Micro Servo SG90
SG90 plastic Horn
plain washers--product grade c gb
hex nuts, style 1-grades ab gb
cross recessed cheese head screws gb x 5
hex thin nuts-grades ab-chamfered gb x 10
cross recessed countersunk head screws gb2 x 2
2.1支撑垫片
30限位螺栓 x 2
20限位螺栓 x 2

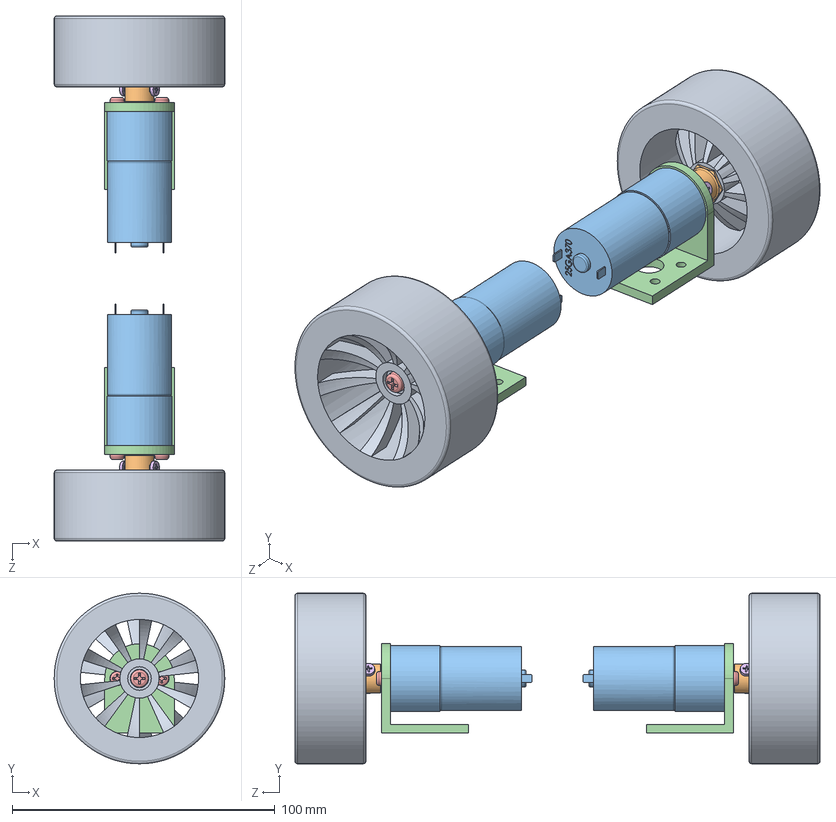
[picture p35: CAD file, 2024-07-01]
往年资料/机电小学期(1)/机电小学期/结题/智能小车3D模型/车轮/车轮部分.SLDASM
65.0 x 65.0 x 200.0 mm
橡胶车轮 x 2
内六角联轴器 x 2
25GA370 x 2
25GA370支撑架 x 2
cross recessed cheese head screws gb x 6
cross recessed cheese head screws type a gb x 4

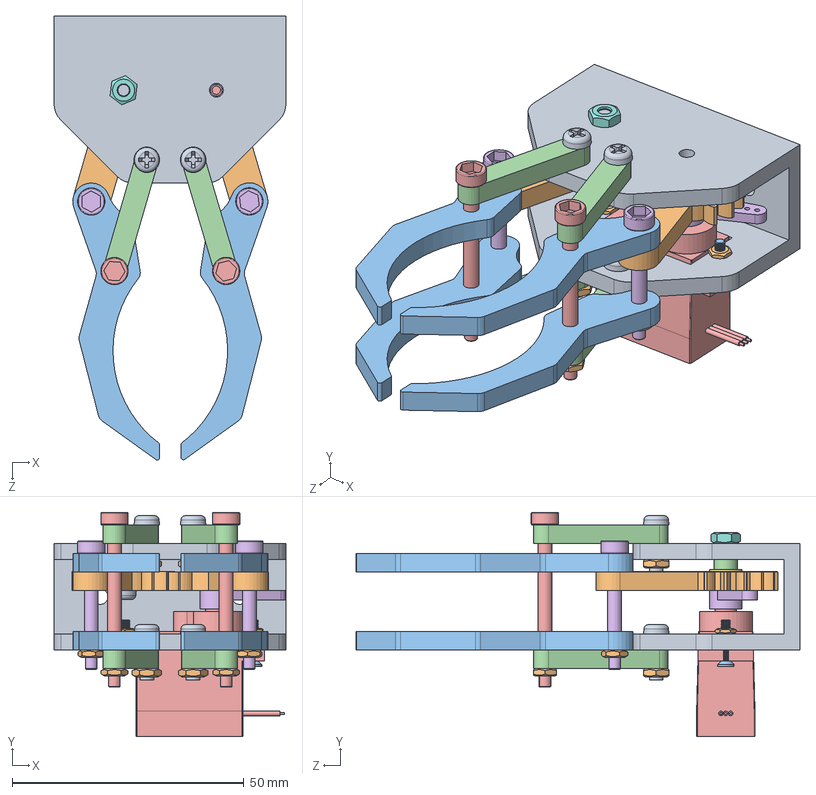
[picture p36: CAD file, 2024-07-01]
往年资料/机电小学期(1)/机电小学期/详细设计/智能小车3D模型/机械臂/机械臂.SLDASM
50.0 x 48.4 x 95.7 mm
支撑板（改）
齿轮传动杆 x 2
机械手爪（改） x 4
连杆（改） x 4
Tower Pro 9g Micro Servo SG90
SG90 plastic Horn
plain washers--product grade c gb
hex nuts, style 1-grades ab gb
cross recessed cheese head screws gb x 5
hex thin nuts-grades ab-chamfered gb x 10
cross recessed countersunk head screws gb2 x 2
2.1支撑垫片
30限位螺栓 x 2
20限位螺栓 x 2

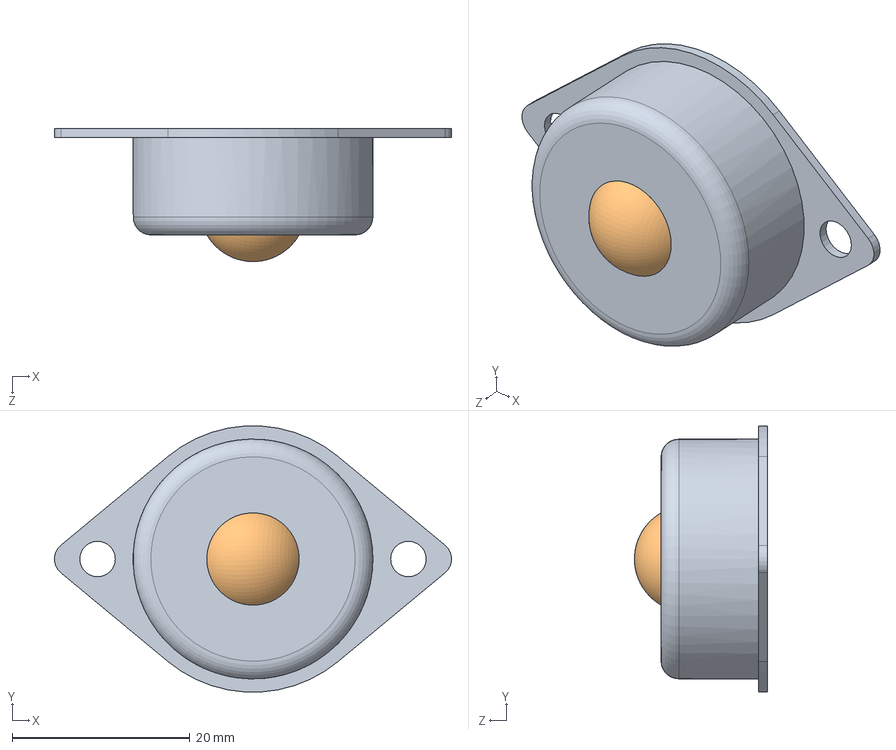
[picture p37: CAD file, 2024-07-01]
往年资料/机电小学期(1)/机电小学期/详细设计/智能小车3D模型/牛眼轮/牛眼轮.SLDASM
44.7 x 29.9 x 15.0 mm
牛眼轮框
牛眼轮心

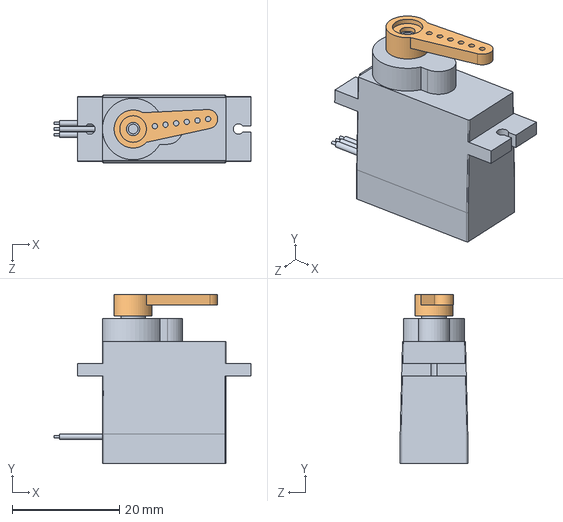
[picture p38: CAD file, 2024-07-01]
往年资料/机电小学期(1)/机电小学期/往年资料/宁梓豪组/小车模型/SG90/SG90.SLDASM
36.7 x 31.5 x 12.6 mm
Tower Pro 9g Micro Servo SG90
SG90 plastic Horn

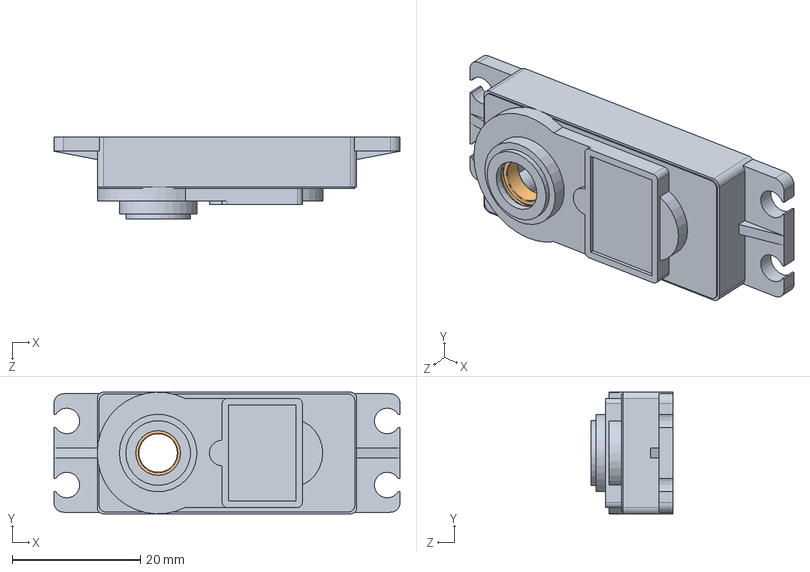
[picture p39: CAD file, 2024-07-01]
往年资料/机电小学期(1)/机电小学期/结题/智能小车3D模型/MG995/tapa servorodamiento.SLDPRT.SLDASM
54.0 x 19.0 x 12.8 mm
tapa servo
radial ball bearing_68_am

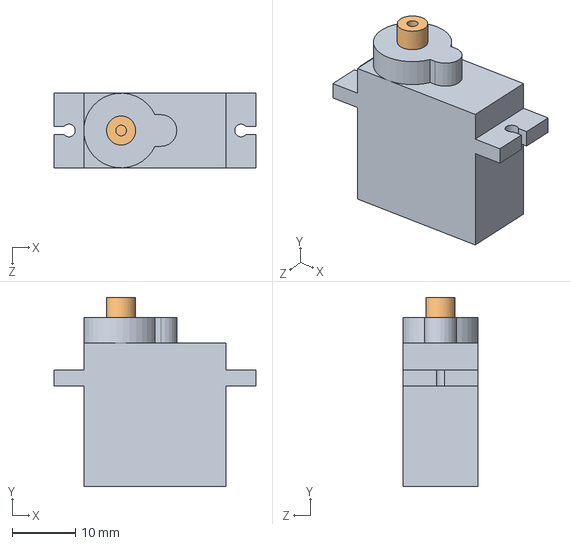
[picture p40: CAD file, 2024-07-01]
往年资料/机电小学期(1)/机电小学期/往年资料/秦立昌组/parts/下载/SG90montaj.SLDASM
31.9 x 29.9 x 11.8 mm
SG90servog_vde
SG90mil

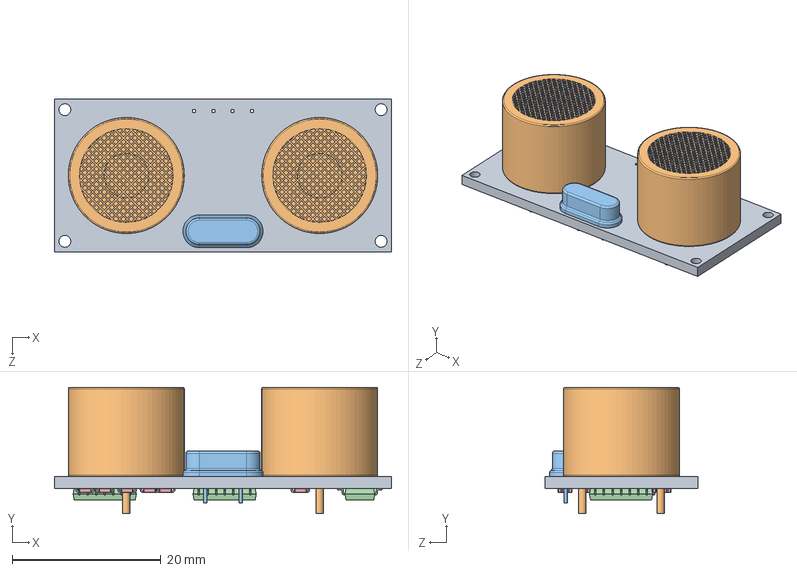
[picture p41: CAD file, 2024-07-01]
往年资料/机电小学期(1)/机电小学期/往年资料/秦立昌组/parts/下载/hc-sr04.SLDASM
45.3 x 17.0 x 20.5 mm
pcb
speaker x 2
osilator
microprocessor_1 x 3
resistor x 14

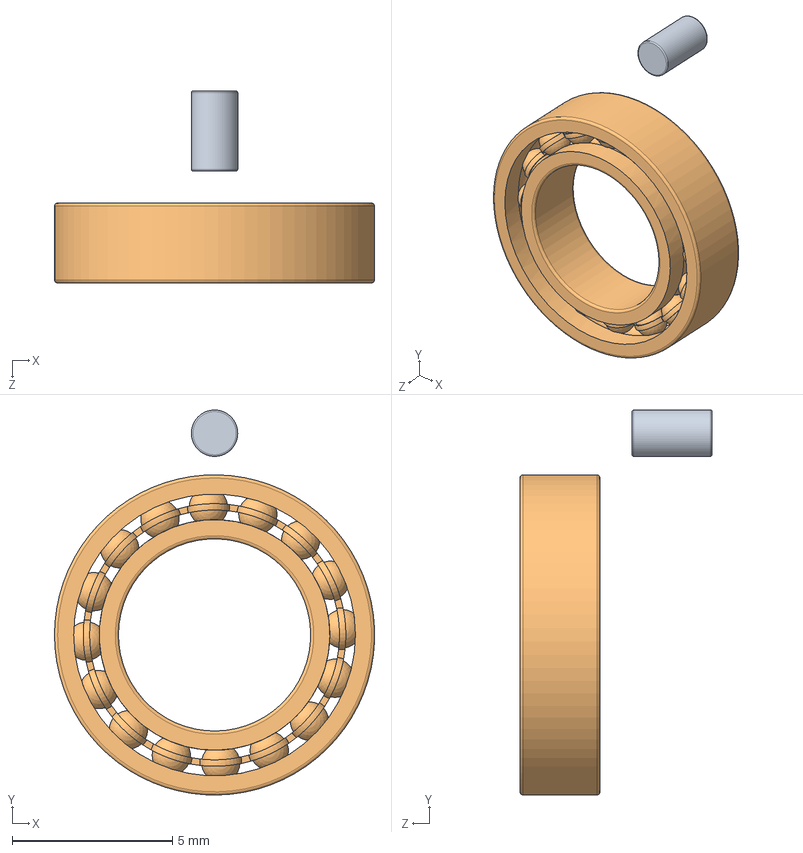
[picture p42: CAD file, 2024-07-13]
MechaDesign/3D Models/egrane2latonpin.SLDPRT.SLDASM
10.00 x 12.0 x 6.00 mm
egrane2latonpin
radial ball bearing_68_am

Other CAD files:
往年资料/机电小学期(1)/机电小学期/详细设计/智能小车3D模型/L298N/L298N.SLDASM
往年资料/机电小学期(1)/机电小学期/结题/智能小车3D模型/L298N/L298N.SLDASM
MechaDesign/2_weid/1connectionF2F3(2).STL
MechaDesign/2_weid/Foundation.DXF
MechaDesign/2_weid/Foundation.SLDPRT
MechaDesign/2_weid/Foundation_down.SLDPRT
MechaDesign/2_weid/OpenMV 支撑架.STL
MechaDesign/2_weid/Upper_fixed_1st.DXF
MechaDesign/2_weid/xianweiluoshuan.SLDPRT
MechaDesign/2_weid/齿轮传动杆.STL
MechaDesign/3D Models/0805.SLDPRT
MechaDesign/3D Models/1040310811_USD1040310811.sldprt
MechaDesign/3D Models/1206.SLDPRT
MechaDesign/3D Models/1connectionF2F3(2).SLDPRT
MechaDesign/3D Models/1connectionF2F3(2).f3d
MechaDesign/3D Models/1connectionF2F3.SLDPRT
MechaDesign/3D Models/2.1支撑垫片.SLDPRT
MechaDesign/3D Models/20限位螺栓.SLDPRT
MechaDesign/3D Models/25GA370.SLDPRT
MechaDesign/3D Models/25GA370支撑架.SLDPRT
MechaDesign/3D Models/30限位螺栓.SLDPRT
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

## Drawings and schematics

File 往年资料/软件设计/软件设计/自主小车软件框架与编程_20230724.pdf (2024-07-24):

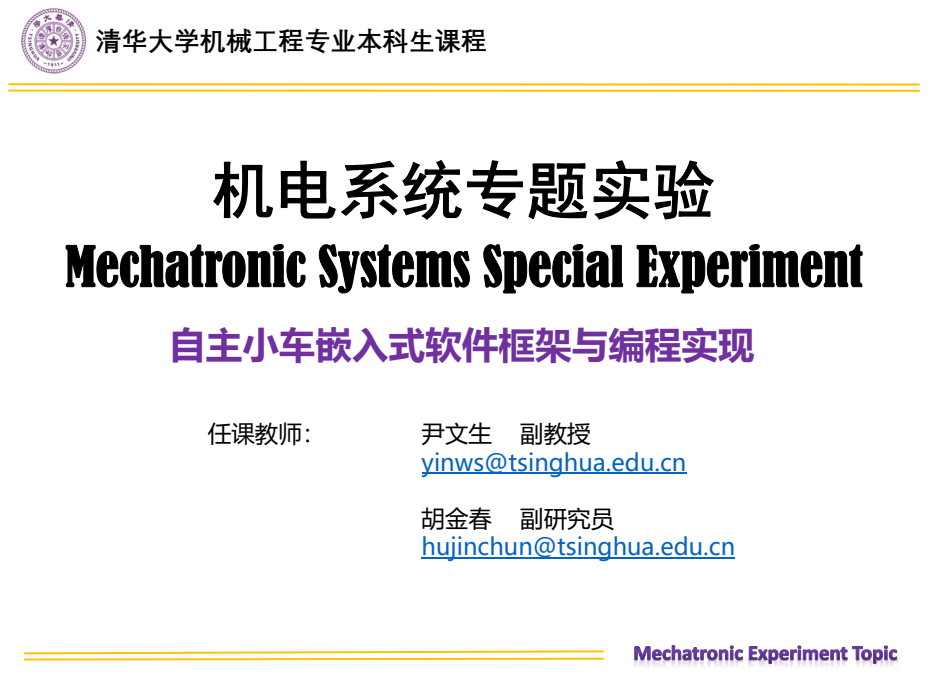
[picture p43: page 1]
清华大学机械工程专业本科生课程; 任课教师：; 尹文生 副教授

机电系统专题实验
Mechatronic Systems Special Experiment
自主小车嵌入式软件框架与编程实现

yinws@tsinghua.edu.cn
胡金春 副研究员
hujinchun@tsinghua.edu.cn

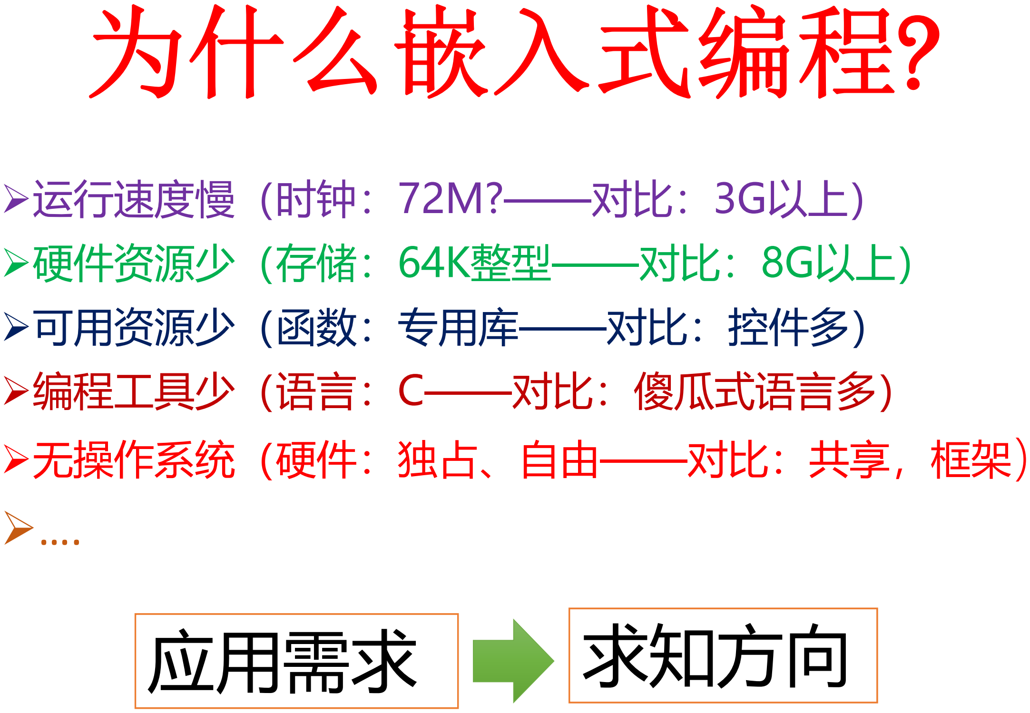
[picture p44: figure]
为什么嵌入式编程; 运行速度慢（时钟：72M?——对比：3G以上） 硬件资源少（存储：64K整型——对比：8G以上） 可用资源少（函数：专用库——对比：控件多） 编程工具少（语言：C——对比：傻瓜式语言多） 无操作系统（硬件：独占、自由——对比：共享，框架 ）; 应用需求; 求知方向

# 课程内容

# - 认识嵌入式编程过程

# - 一般嵌入式编程变量管理

# - 车控系统软件建议框架

# - 车轮转速控制实现

# - PID控制律参数与调试

# 课程内容

## - 认识嵌入式编程过程 - 一般嵌入式编程变量管理 - 车控系统软件建议框架 - 车轮转速控制实现 - PID控制律参数与调试

### 通过4个过程生成可执行代码，通过仿真器与集成开发环境帮助下下载并运行。

# 嵌入式编程过程：预处理、编译、汇编和链接

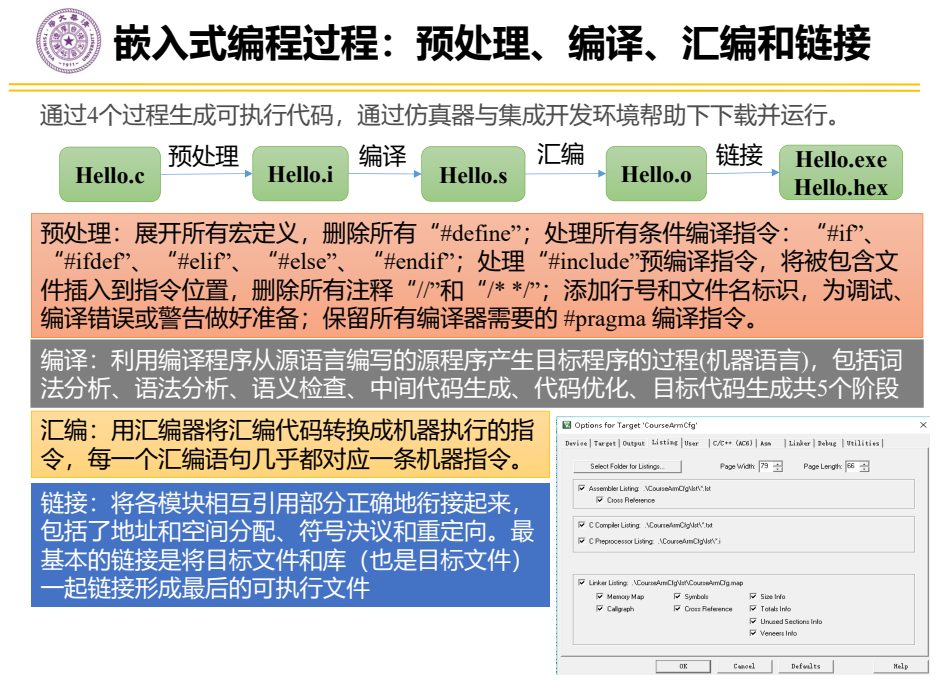
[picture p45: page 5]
Hello.o; Hello.exe Hello.hex

Hello.s 编译 Hello.i 预处理

Hello.c
预处理：展开所有宏定义，删除所有“#define”；处理所有条件编译指令：“#if”、
“#ifdef”、“#elif”、“#else”、“#endif”；处理“#include”预编译指令，将被包含文
件插入到指令位置，删除所有注释“//”和“/* */”；添加行号和文件名标识，为调试、
编译错误或警告做好准备；保留所有编译器需要的 #pragma 编译指令。
编译：利用编译程序从源语言编写的源程序产生目标程序的过程(机器语言)，包括词
法分析、语法分析、语义检查、中间代码生成、代码优化、目标代码生成共5个阶段
汇编：用汇编器将汇编代码转换成机器执行的指
令，每一个汇编语句几乎都对应一条机器指令。
链接：将各模块相互引用部分正确地衔接起来，
包括了地址和空间分配、符号决议和重定向。最
基本的链接是将目标文件和库（也是目标文件）
一起链接形成最后的可执行文件

## 源文件

## 源文件

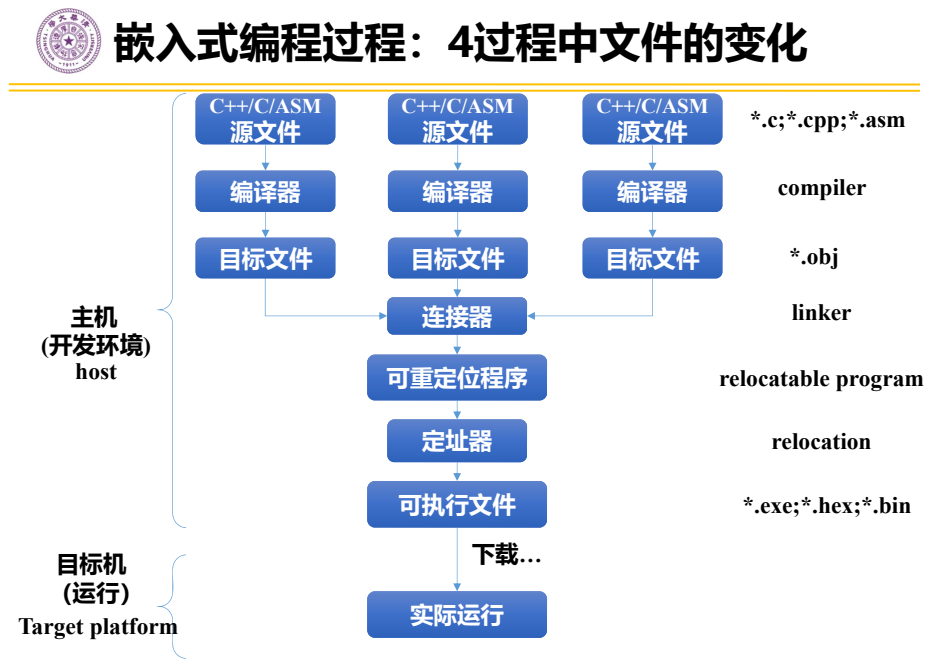
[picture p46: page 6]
可重定位程序; 定址器; 可执行文件; *.c;*.cpp;*.asm; compiler; *.obj; linker; relocatable program; relocation; 主机 (开发环境); 目标机; 实际运行; C++/C/ASM; 编译器; 目标文件; 连接器; C++/C/ASM 源文件; Target platform; host; 嵌入式编程过程：4过程中文件的变化

*.exe;*.hex;*.bin

# 课程内容

## - 认识嵌入式编程过程 - 认识嵌入式编程变量管理 - 车控系统软件建议框架 - 车轮转速控制实现 - PID控制律的参数与调试

# 嵌入式编程变量：C语言几种数据类型

# - 动态存储与静态存储

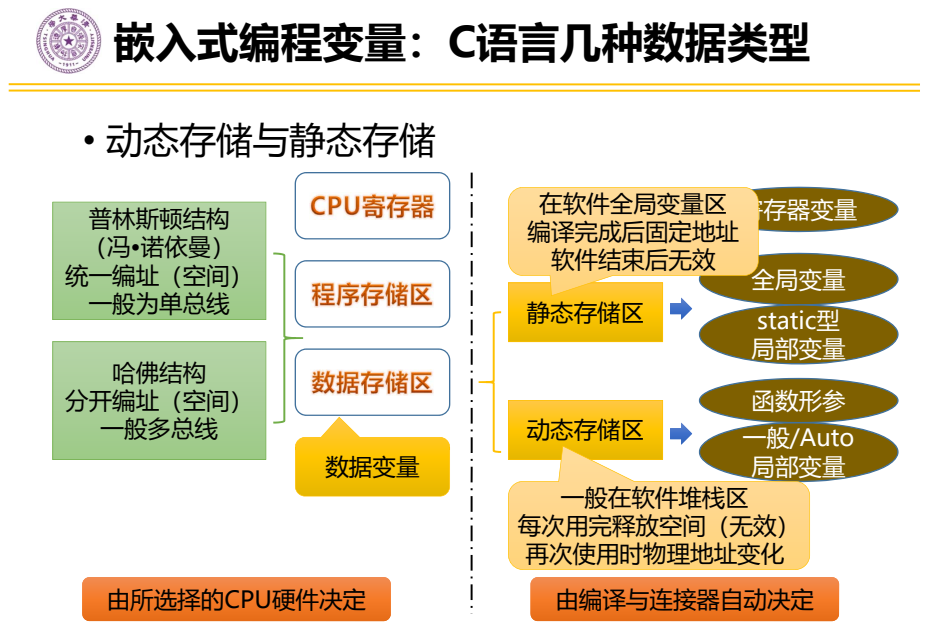
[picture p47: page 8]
普林斯顿结构 （冯•诺依曼） 统一编址（空间） 一般为单总线; 哈佛结构 分开编址（空间） 一般多总线; 由所选择的CPU硬件决定; 由编译与连接器自动决定; 全局变量 static型 局部变量; 一般/Auto 局部变量; 函数形参; 寄存器变量; 静态存储区; 动态存储区; 数据变量; 在软件全局变量区 编译完成后固定地址 软件结束后无效; 一般在软件堆栈区 每次用完释放空间（无效） 再次使用时物理地址变化

- 避免模块之间复制传递
- 函数参数调用时被复制，增加存储负担与时间成本
- 变量范围与表示
- 关注变量的表示范围、符号，避免表示溢出
- 根据CPU实际支持数值类型与位数合理确定变量类型：8位51单片机尽可能使用char（有符号） 与unsigned char(无符号)变量，float变量计算极其费CPU时间
- 连续运算可能导致编译器错误编译（并不提示）
- 如将k=a*b*c*d替换为k1=a*b; k2=c*d; k=k1*k2
- 嵌入式CPU存储空间较小，避免越界带来的程序“乱窜”
- 注意数组所定义空间大小
- 合理分配堆栈空间大小
- 注意实际使用内存空间大小

## 尽可能定义较少全局与局部变量：较少的变量，不会致空间不够

### 尽可能使用全局变量：全局变量区域较大，编译器会越界检查；堆栈区较小， 编译器难以检查，越界后果难料 合理组织全局变量与软件框架：提高全局变量利用率同时避免耦合

# 嵌入式编程变量：变量在内存中的占用

- 一般地：char: 8Bits, -128~+127, unsigned char: 8Bits, 0~+255
- 不同编译器变量表示字节数与范围不同，实际使用前应首先测试确认 VarSize = sizeof(unsigned char)
- 不是所有编译器支持所有常用变量类型：如在32位DSP上实际用16Bits表示char
DSP28338: char(2Bytes), float(4Bytes), VC: char(1Byte) float(4Bytes) STm32: uint8_t(1Bytes)
- 如变量超过表示范围，则溢出导致不可预测后果：如10*100赋予char，结果可能是-8。 解决方法：1）设计时考虑变量表示范围；2）使用前限制范围；3）其他数据类型转换

# 嵌入式编程变量：表示范围与溢出

# 嵌入式编程变量：全局变量应用模型

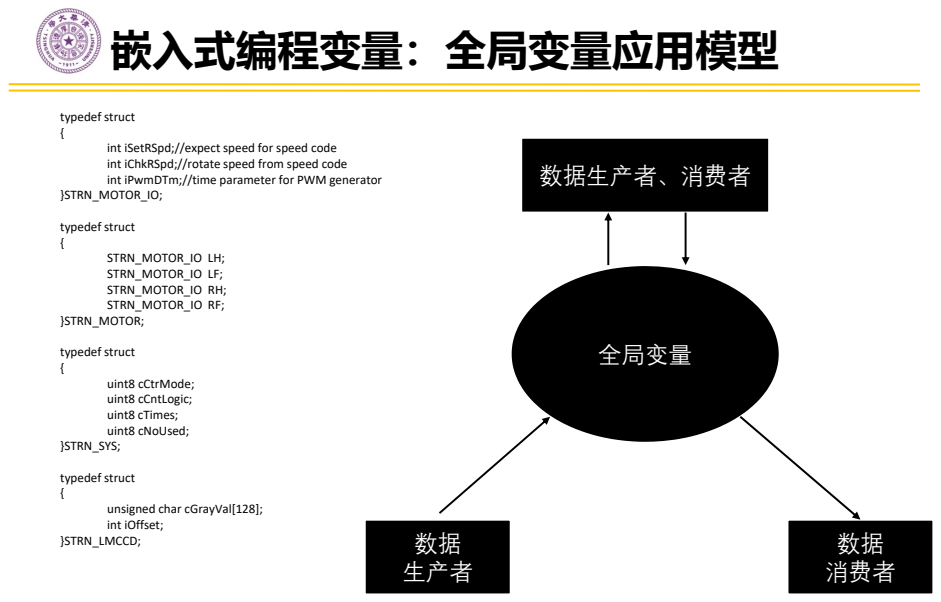
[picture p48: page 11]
全局变量; 数据 生产者; 数据 消费者; 数据生产者、消费者; typedef struct {; }STRN_MOTOR_IO;; STRN_MOTOR_IO LH; STRN_MOTOR_IO LF; STRN_MOTOR_IO RH; STRN_MOTOR_IO RF; }STRN_MOTOR;; uint8 cCtrMode; uint8 cCntLogic; uint8 cTimes; uint8 cNoUsed; }STRN_SYS;; }STRN_LMCCD;

int iSetRSpd;//expect speed for speed code
int iChkRSpd;//rotate speed from speed code
int iPwmDTm;//time parameter for PWM generator

unsigned char cGrayVal[128];
int iOffset;

# 嵌入式编程变量：函数与变量定义与引用

### 变量（定义）声明：

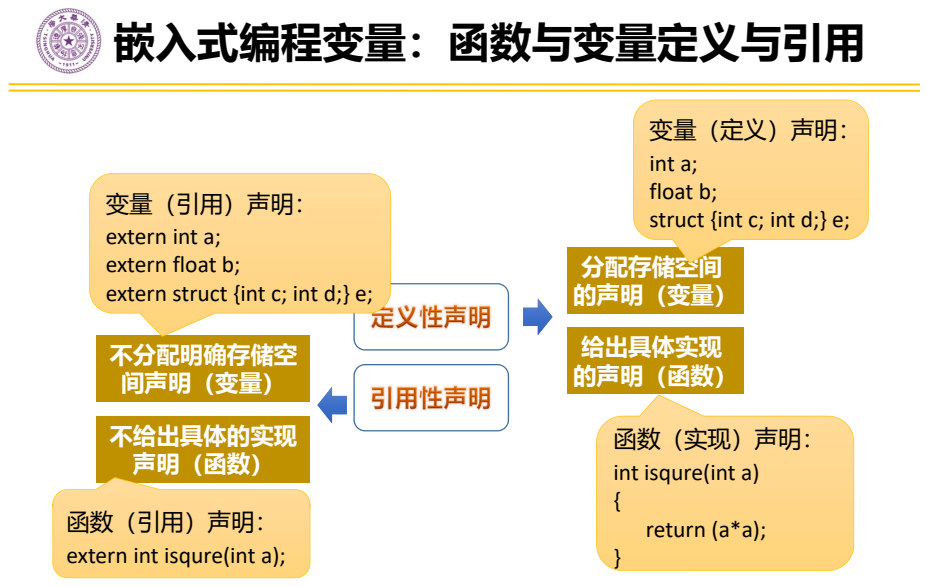
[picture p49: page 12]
int isqure(int a) {; return (a*a);

int a;
float b;
struct {int c; int d;} e;
分配存储空间
的声明（变量）
给出具体实现
的声明（函数）

extern int a;
extern float b;
extern struct {int c; int d;} e;
不分配明确存储空
间声明（变量）
不给出具体的实现

extern int isqure(int a);

# 嵌入式编程变量：两个C文件实例

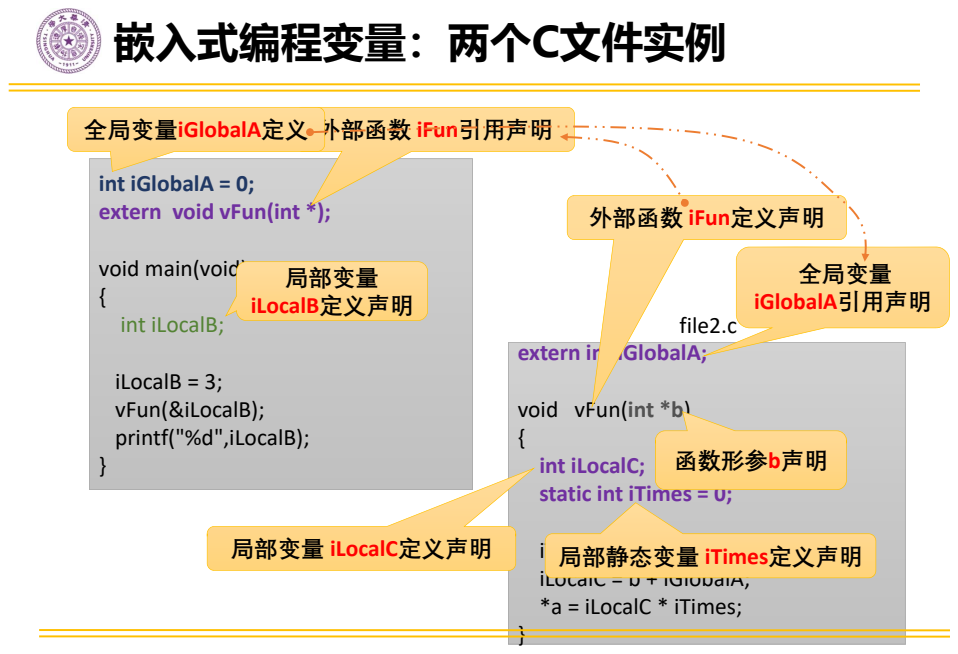
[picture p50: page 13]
iLocalB = 3; vFun(&iLocalB); printf("%d",iLocalB);; iTimes = iTimes + 1; iLocalC = b + iGlobalA; *a = iLocalC * iTimes;; file1.c; file2.c; 函数形参; b声明; 外部函数 iFun引用声明; 外部函数 iFun定义声明; 局部变量 iLocalB定义声明; 局部变量 iLocalC定义声明; 局部静态变量 iTimes定义声明; 全局变量iGlobalA定义; 全局变量 iGlobalA引用声明

int iGlobalA = 0;
extern void vFun(int *);

void main(void)
int iLocalB;

extern int iGlobalA;

void vFun(int *b)
int iLocalC;
static int iTimes = 0;

# 嵌入式编程变量：结构体数据类型

# - 结构体

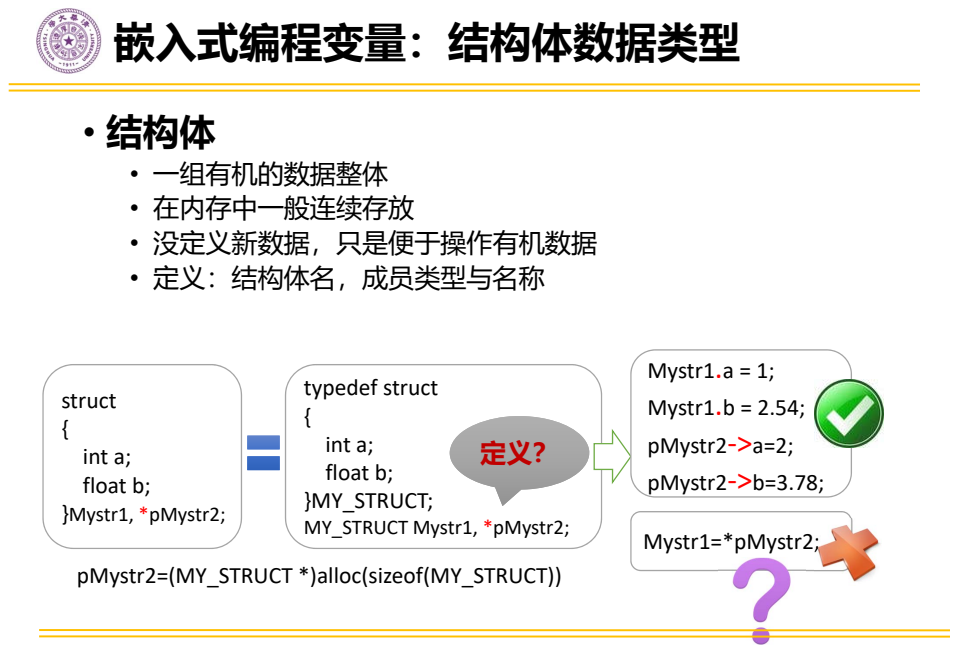
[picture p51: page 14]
struct {; int a; float b; }Mystr1,; *pMystr2;; typedef struct {; int a; float b; }MY_STRUCT; MY_STRUCT Mystr1,; Mystr1.a = 1;; Mystr1.b = 2.54;; pMystr2‐>a=2;; pMystr2‐>b=3.78;; Mystr1=*pMystr2;; pMystr2=(MY_STRUCT *)alloc(sizeof(MY_STRUCT))

• 一组有机的数据整体
• 在内存中一般连续存放
• 没定义新数据，只是便于操作有机数据
• 定义：结构体名，成员类型与名称

# 嵌入式编程变量：结构体类型数据传递

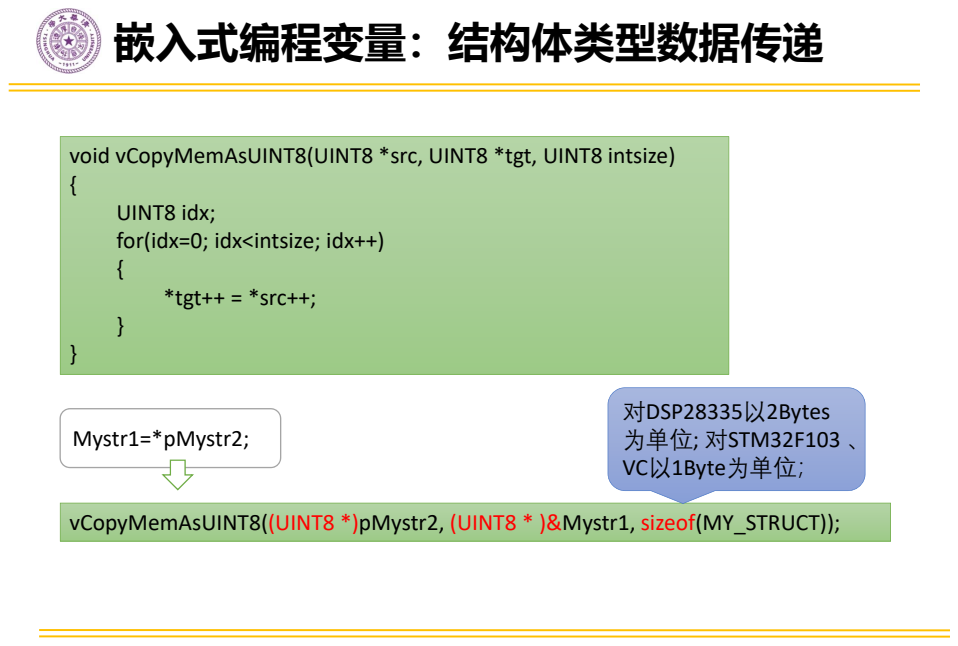
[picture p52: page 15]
vCopyMemAsUINT8((UINT8 *)pMystr2, (UINT8 * )&Mystr1, sizeof(MY_STRUCT));; Mystr1=*pMystr2;; 对DSP28335; 以2Bytes 为单位; 对STM32F103 、 VC; 以1Byte为单位；

void vCopyMemAsUINT8(UINT8 *src, UINT8 *tgt, UINT8 intsize)
UINT8 idx;
for(idx=0; idx<intsize; idx++)
*tgt++ = *src++;

# 课程内容

## - 认识嵌入式编程过程 - 认识嵌入式编程变量管理 - 车控系统软件建议框架 - 车轮转速控制实现 - PID控制律的参数与调试
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

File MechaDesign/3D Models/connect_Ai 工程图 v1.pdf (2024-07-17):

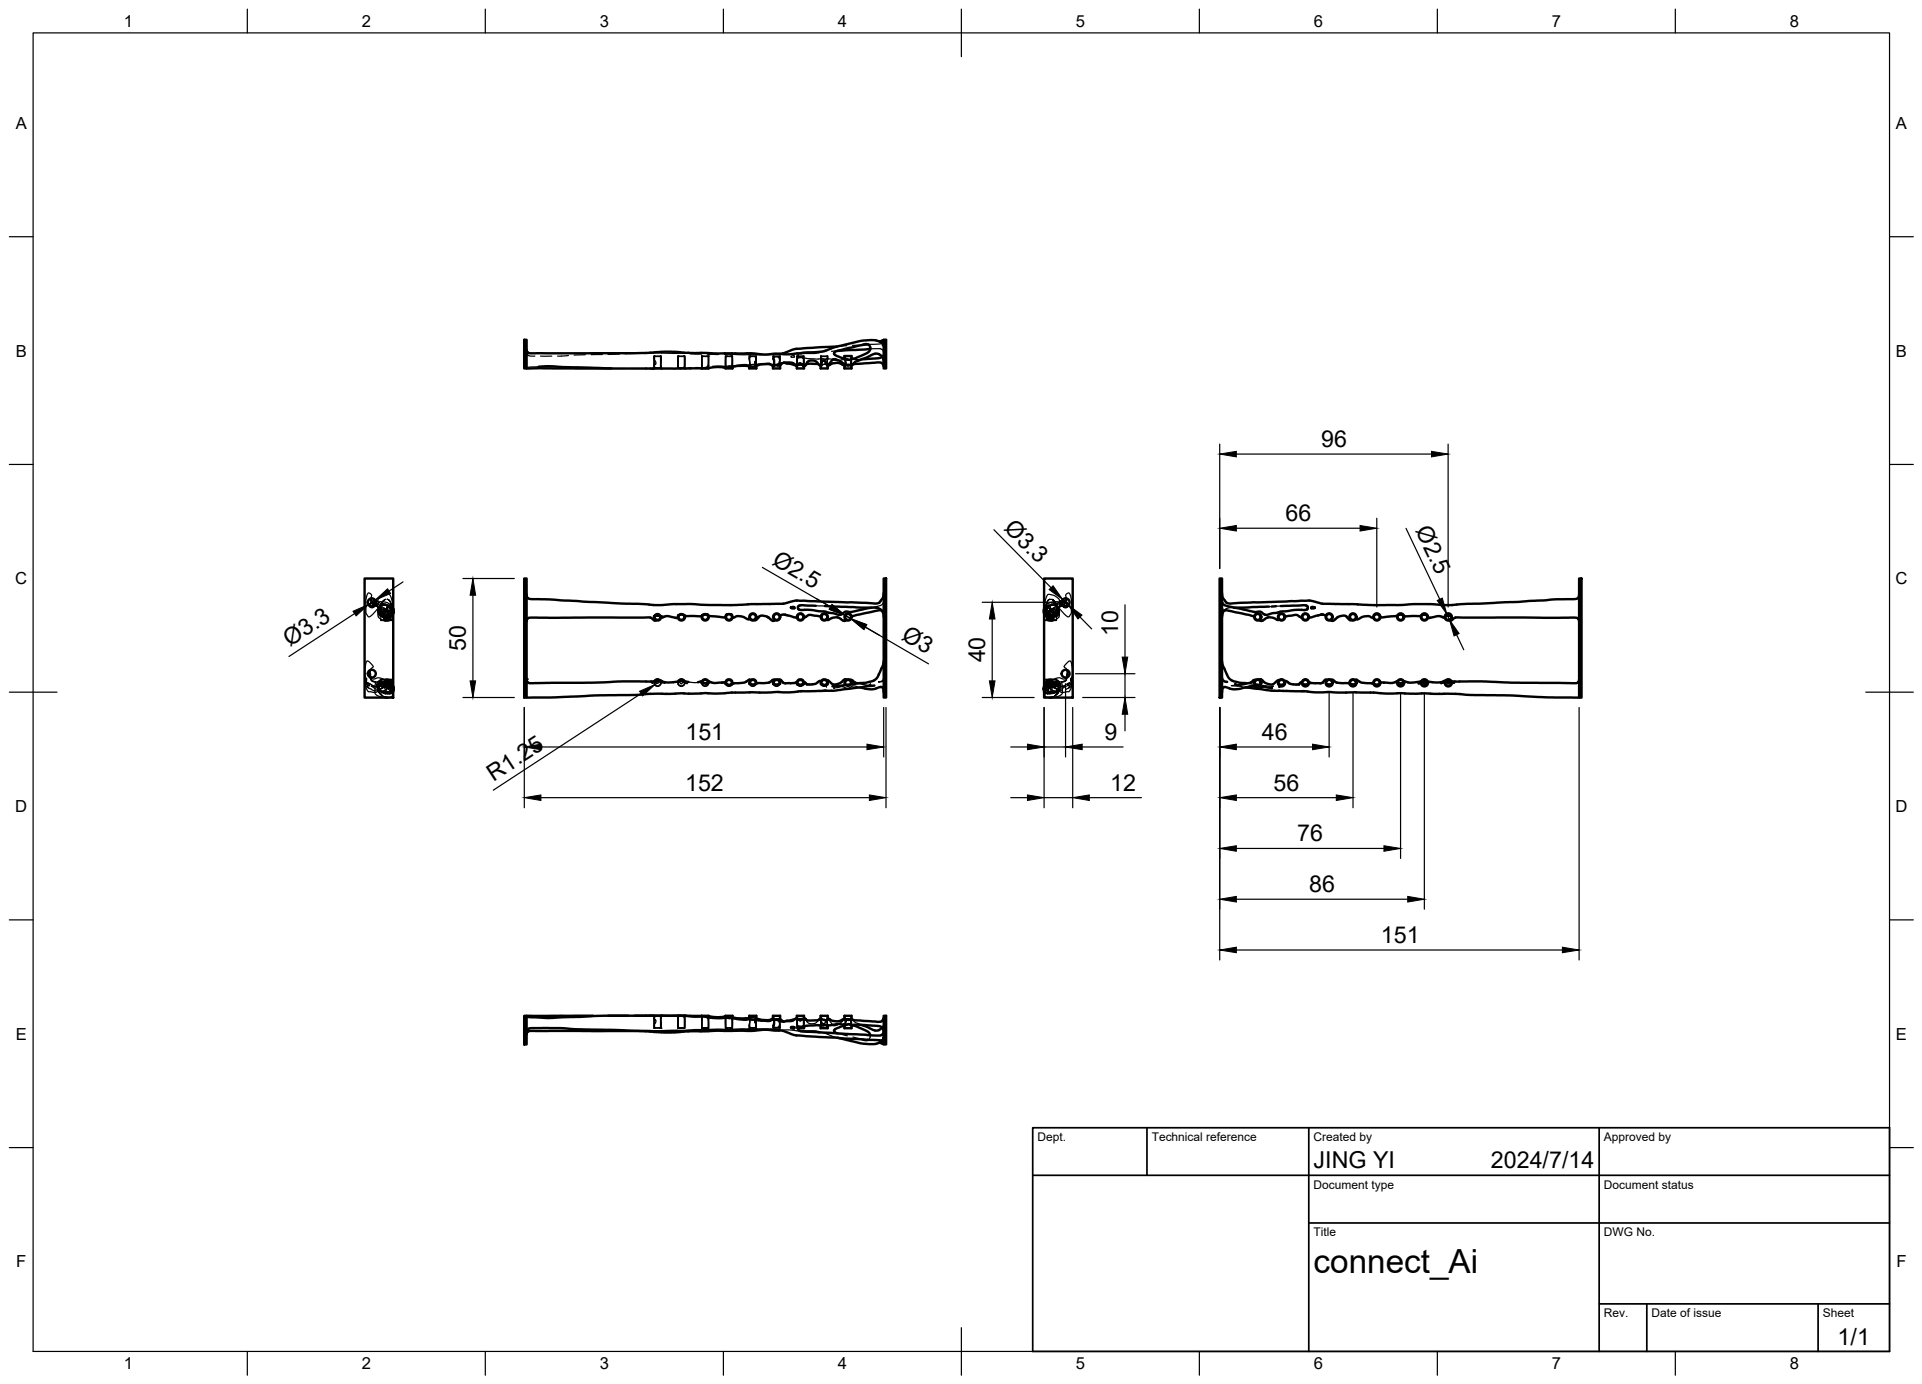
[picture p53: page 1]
Title; DWG No.; Rev.; Date of issue; Sheet; JING YI 50

Dept. | Technical reference | Created by 2024/7/14 | Approved by

Document type | Document status

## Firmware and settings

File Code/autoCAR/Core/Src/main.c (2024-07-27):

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
/* Includes ------------------------------------------------------------------*/
#include "main.h"
#include "dma.h"
#include "iwdg.h"
#include "tim.h"
#include "usart.h"
#include "gpio.h"

/* USER CODE BEGIN Includes */
#include "motor.h"
#include "ultraSonic.h"
#include "timersInit.h"
#include "string.h"
#include "servo.h"
extern int float_to_uint8_arry(uint8_t* u8Arry, float floatdata, int precision);
extern float uint8_to_float(uint8_t* u8arry, int point_length);
/* USER CODE END Includes */


/* USER CODE BEGIN PV */
float rpmRight=0,rpmLeft=0,deriSpeed=0,centralSpeed;
uint8_t rxDataBT[50];
uint8_t rxDataOp[50];
int countnum_rightcircuance=0;
int countnum_leftcircuance=0;
float currentLeft=0,currentRight=0;
extern int pulseLeft,pulseRight;
extern int ultraLoop;int mode=0;
extern uint8_t cRt[256];
float craw_state=0,is_crawed=0,is_put=0;
/* USER CODE END PV */

void SystemClock_Config(void);
/**
  * @brief  The application entry point.
  * @retval int
  */
int main(void)
{

  /* MCU Configuration--------------------------------------------------------*/

  /* Reset of all peripherals, Initializes the Flash interface and the Systick. */
  HAL_Init();

  /* Configure the system clock */
  SystemClock_Config();

  /* Initialize all configured peripherals */
  MX_GPIO_Init();
  MX_DMA_Init();
  MX_TIM2_Init();
  MX_TIM4_Init();
  MX_TIM5_Init();
  MX_TIM1_Init();
  MX_UART5_Init();
  MX_UART4_Init();
  MX_TIM7_Init();
  MX_TIM3_Init();
  MX_TIM8_Init();
  MX_TIM6_Init();
  MX_TIM10_Init();
  MX_TIM12_Init();
  //MX_IWDG_Init();
  /* USER CODE BEGIN 2 */
  	/*HAL_TIM_PWM_Start(&htim5, TIM_CHANNEL_ALL);//�?????????????????启电机PWM，最�?????????????????255
  	HAL_TIM_PWM_Start(&htim1, TIM_CHANNEL_ALL);//�?????????????????启舵机PWM，最�?????????????????1999
  	HAL_TIM_Encoder_Start(&htim2, TIM_CHANNEL_ALL);//左轮编码�?????????????????
  	HAL_TIM_Encoder_Start(&htim4, TIM_CHANNEL_ALL);//右轮编码�?????????????????
  	HAL_TIM_Base_Start_IT(&htim7);//中断定时器，50ms�?????????????????次中�?????????????????*/


  //turning_theta_Servo2=Servo2_init(turning_theta_Servo2);

  //turning_theta_Servo2=Servo2_puting(turning_theta_Servo2);

  //turning_theta_Servo1=Servo1_craw(turning_theta_Servo1);

  //turning_theta_Servo2=Servo2_driving(turning_theta_Servo2);



  /*turning_theta_Servo3=Servo3_init(turning_theta_Servo3);*/
  timersInit();
  __HAL_TIM_SET_COUNTER(&htim2,32768);
   __HAL_TIM_SET_COUNTER(&htim4,32768);
   //float turning_theta_Servo1=50;
   //float turning_theta_Servo2=25;
  // float turning_theta_Servo3=55;
   //turning_theta_Servo1=Servo1_init(turning_theta_Servo1);
   //turning_theta_Servo2=Servo2_init(turning_theta_Servo2);

   //craw_up_trail(1);

   //put_down_trail(1);
  HAL_UARTEx_ReceiveToIdle_DMA(&huart5, rxDataBT, sizeof rxDataBT);
  HAL_UARTEx_ReceiveToIdle_DMA(&huart4, rxDataOp, sizeof rxDataOp);
  //Servo_turn(2,60,25);
  //Servo_turn(1,120,25);
  /* USER CODE END 2 */

  /* Infinite loop */
  /* USER CODE BEGIN WHILE */
  while (1)
  {
	  setLeftPWM(pulseLeft,TIM_CHANNEL_3);
	  setRightPWM(pulseRight,TIM_CHANNEL_4);
	  if(craw_state==1){
		  is_crawed=craw_up_trail(1);//if_crow==1时，调用循迹时的程序；if_crow==2时，调用避障时的程序
	  }
	  else if(craw_state==2){
		  //if_crow==1时，调用循迹时的程序；if_crow==2时，调用避障时的程序
		  is_put=put_down_trail(1);
	  }

	  if (is_crawed==1){
		  //setSpin(20, 'F');
		  centralSpeed = 60;
		  rpmLeft=rpmRight=centralSpeed;
		  mode=1;
		  is_crawed=0;

	  }else if (is_put==1){
		  is_put=0;
	  }
	  /*
	  turning_theta_Servo1=Servo1_craw(turning_theta_Servo1);
	  turning_theta_Servo2=Servo2_driving(turning_theta_Servo2);
	  turning_theta_Servo1=Servo1_put(turning_theta_Servo1);
	  turning_theta_Servo2=Servo2_puting(turning_theta_Servo2);                                                                                                                                                                                                                                  	  setLeftPWM(pulseLeft,TIM_CHANNEL_3);
	  setRightPWM(pulseRight,TIM_CHANNEL_4);*/
	  if (ultraLoop==0){
	  	distanceFront=MeasureDistance(&ultraSonicFront);
	  }else if(ultraLoop==1){
	  	 distanceLeft=MeasureDistance(&ultraSonicLeft);
	  }else if (ultraLoop==2){
	  	 distanceRight=MeasureDistance(&ultraSonicRight);
}
	  if (ultraLoop<3){ultraLoop++;}
	  else{ultraLoop=0;}
    /* USER CODE END WHILE */

    /* USER CODE BEGIN 3 */
  }
  /* USER CODE END 3 */
}

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


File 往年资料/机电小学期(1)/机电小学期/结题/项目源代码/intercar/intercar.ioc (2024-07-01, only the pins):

Mcu.UserName=STM32F103VETx
PC10.Signal=UART4_TX
PB11.Signal=USART3_RX
PB13.Signal=GPIO_Output
PE6.GPIO_Label=TRIG2
PD13.Signal=S_TIM4_CH2
PC7.Signal=S_TIM8_CH2
PE5.Signal=GPIO_Output
PE1.Signal=GPIO_Output
PE13.Signal=S_TIM1_CH3
PE9.Signal=S_TIM1_CH1
PE2.Signal=GPIO_Output
PE4.Signal=GPIO_Output
PD12.Signal=S_TIM4_CH1
PA10.Signal=USART1_RX
PA4.GPIO_Label=TRIG3
PD15.Signal=S_TIM4_CH4
PA3.Signal=S_TIM5_CH4
PC11.Signal=UART4_RX
PC6.Signal=S_TIM8_CH1
PA0-WKUP.Signal=S_TIM2_CH1_ETR
PA13.Signal=SYS_JTMS-SWDIO
PA9.Signal=USART1_TX
PE11.Signal=S_TIM1_CH2
PA1.Signal=S_TIM2_CH2
PB10.Signal=USART3_TX
PA5.Signal=GPIO_Output
PE14.Signal=S_TIM1_CH4
PE6.Signal=GPIO_Output
PA2.Signal=S_TIM5_CH3
PD14.Signal=S_TIM4_CH3
PA4.Signal=GPIO_Output
PA5.GPIO_Label=TRIG4
PE5.GPIO_Label=TRIG1
PA14.Signal=SYS_JTCK-SWCLK
PE3.Signal=GPIO_Output

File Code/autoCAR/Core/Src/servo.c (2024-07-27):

/*
 * servo.c
 *
 *  Created on: Jul 17, 2024
 *      Author: DELL
 */
#include "servo.h"
#include "tim.h"
//Servo1 是夹爪夹取电机
TIM_HandleTypeDef *Servo1 = &htim1;
uint32_t Servo1_Channel = TIM_CHANNEL_2;
//Servo2 是夹爪转动电机 Mg995
TIM_HandleTypeDef *Servo2=&htim1;
uint32_t Servo2_Channel = TIM_CHANNEL_1;
//Servo3 是openMV转动电机
TIM_HandleTypeDef *Servo3=&htim1;
uint32_t Servo3_Channel = TIM_CHANNEL_3;
//下面是各个电机转动的总函数
extern int craw_state;
float Servo_turn(int servo_number,float turning_theta,float turning_theta_0){
	float turning_time = 0;
	float turning_t=0;
	float turning_time1 = 0;
	float turning_t1=0;
	//uint32_t waiting_time_servo=0;
	turning_time=turning_theta/90;
	turning_time1=turning_theta_0/90;
	//waiting_time_servo=turning_time*waiting_time_servo_max;
	turning_time=turning_time+0.5;
	turning_time1=turning_time1+0.5;
	turning_t=turning_time*1000;
	turning_t1=turning_time1*1000;

	if(turning_theta>180){
		return 0;
	}
	float turning_time2=0;//真正转过的角度
	turning_time2=turning_t-turning_t1;
	float turning_theta2=0;
	turning_theta2=turning_theta-turning_theta_0;
	if(turning_time2>0){
	float p=turning_theta2;
	p=p/180;
	p=p*60;
	int delay_time=0;
	delay_time=(int)p;
if(servo_number==1){
	for(float i=0;i<turning_time2;i+=turning_time2/15){
		__HAL_TIM_SET_COMPARE(Servo1,Servo1_Channel,(uint32_t)(turning_t));
		HAL_Delay(delay_time);
	}

}
else if(servo_number==2){
	for(float i=0;i<turning_time2;i+=turning_time2/15){
			__HAL_TIM_SET_COMPARE(Servo2,Servo2_Channel,(uint32_t)(turning_t));
	HAL_Delay(delay_time);
		}
}
else if(servo_number==3){
	for(float i=0;i<turning_time2;i+=turning_time2/15){
			__HAL_TIM_SET_COMPARE(Servo3,Servo3_Channel,(uint32_t)(turning_t));
	HAL_Delay(delay_time);
		}
}
else{
	return 0;
}
	}
	else{
		float p=-turning_theta2;
			p=p/180;
			p=p*250;
			int delay_time=0;
			delay_time=(int)p;
	if(servo_number==1){
		for(float i=0;i>turning_time2;i+=turning_time2/15){
			__HAL_TIM_SET_COMPARE(Servo1,Servo1_Channel,(uint32_t)(i+turning_t1));
			HAL_Delay(delay_time);
		}

	}
	else if(servo_number==2){
		for(float i=0;i>turning_time2;i+=turning_time2/15){
				__HAL_TIM_SET_COMPARE(Servo2,Servo2_Channel,(uint32_t)(i+turning_t1));
			HAL_Delay(delay_time);
			}
	}
	else if(servo_number==3){
		for(float i=0;i>turning_time2;i+=turning_time2/15){
				__HAL_TIM_SET_COMPARE(Servo3,Servo3_Channel,(uint32_t)(i+turning_t1));
				HAL_Delay(delay_time);
		}
	}
	else{
		return 0;
	}
		}


return turning_theta;
}
//下面是Servo1的各项函数
float Servo1_init(float turning_theta_0){
	//HAL_TIM_PWM_Start(Servo1,Servo1_Channel);
	float init_data=Servo1_initial_data;
	float whe_w=0;
	whe_w=Servo_turn(1,init_data,turning_theta_0);
	return whe_w;
}
float Servo1_craw(float turning_theta_0){
		float craw_data=Servo1_craw_theta;
		float whe_w=0;
		whe_w=Servo_turn(1,craw_data,turning_theta_0);
		return whe_w;
}
float Servo1_put(float turning_theta_0){
			float put_data=Servo1_put_down_theta;
			float whe_w=0;
			whe_w=Servo_turn(1,put_data,turning_theta_0);
			return whe_w;
}
//下面是Servol2的各项函数
float Servo2_init(float turning_theta_0){
	//HAL_TIM_PWM_Start(Servo2,Servo2_Channel);
		float init_data=Servo2_initial_data;
		float whe_w=0;
		whe_w=Servo_turn(2,init_data,turning_theta_0);
		return whe_w;
}
float Servo2_driving(float turning_theta_0){
			float drive_data=Servo2_driving_theta;
			float whe_w=0;
			whe_w=Servo_turn(2,drive_data,turning_theta_0);
			return whe_w;
}
float Servo2_puting(float turning_theta_0){
			float put_data=Servo2_puting_theta;
			float whe_w=0;
			whe_w=Servo_turn(2,put_data,turning_theta_0);
			return whe_w;
}
//下面是Servol3的各项函数
float Servo3_init(float turning_theta_0){
	HAL_TIM_PWM_Start(Servo3,Servo3_Channel);
		float init_data=Servo3_initial_data;
		float whe_w=0;
		whe_w=Servo_turn(3,init_data,turning_theta_0);
		return whe_w;
}
float Servo3_driving(float turning_theta_0){
			float drive_data=Servo3_driving_theta;
			float whe_w=0;
			whe_w=Servo_turn(3,drive_data,turning_theta_0);
			return whe_w;
}
float Servo3_puting(float turning_theta_0){
			float put_data=Servo3_puting_theta;
			float whe_w=0;
			whe_w=Servo_turn(3,put_data,turning_theta_0);
			return whe_w;
}
float craw_up_trail(int if_crow){
	if(if_crow==1){

		float turning_theta_crow_1_S2=Servo2_initial_data;
		turning_theta_crow_1_S2=Servo_turn(2,60,25);
		float turning_theta_crow_1_S1=Servo1_initial_data;
		turning_theta_crow_1_S1=Servo1_put(turning_theta_crow_1_S1);
		turning_theta_crow_1_S2=Servo2_puting(turning_theta_crow_1_S2);
		turning_theta_crow_1_S1=Servo1_craw(turning_theta_crow_1_S1);
		turning_theta_crow_1_S2=Servo2_driving(turning_theta_crow_1_S2);
		craw_state=0;
		return 1;
	}
	else return 0;
}
float put_down_trail(int if_put){

	if(if_put==1){

			float turning_theta_crow_1_S2=Servo2_driving_theta;
			float turning_theta_crow_1_S1=Servo1_craw_theta;
			turning_theta_crow_1_S2=Servo2_puting(turning_theta_crow_1_S2);
			turning_theta_crow_1_S1=Servo1_put(turning_theta_crow_1_S1);
			turning_theta_crow_1_S2=Servo_turn(2,60,turning_theta_crow_1_S2);
			turning_theta_crow_1_S1=Servo1_craw(turning_theta_crow_1_S1);
			turning_theta_crow_1_S2=Servo2_driving(turning_theta_crow_1_S2);
			craw_state=0;
			return 1;
		}
		else return 0;
}

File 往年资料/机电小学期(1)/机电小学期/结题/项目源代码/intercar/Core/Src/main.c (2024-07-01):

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
/* Includes ------------------------------------------------------------------*/
#include "main.h"
#include "tim.h"
#include "usart.h"
#include "gpio.h"

/* USER CODE BEGIN Includes */
#include "motor.h"
#include "servo.h"
#include "control.h"
#include "sonic.h"
#include "bluetooth.h"
#include "openmv.h"
#include "imu.h"
#include <stdio.h>
#include <math.h>
/* USER CODE END Includes */


/* USER CODE BEGIN PV */
uint8_t IS_FIRDT_CAPTURED;
uint8_t USART1_RXbuff;
uint16_t echo1=0;
uint16_t echo2=0;
uint16_t count=0;
int i=0;
UART_HandleTypeDef huart3;
/* USER CODE END PV */

void SystemClock_Config(void);
/**
  * @brief  The application entry point.
  * @retval int
  */
int main(void)
{
  /* MCU Configuration--------------------------------------------------------*/

  /* Reset of all peripherals, Initializes the Flash interface and the Systick. */
  HAL_Init();

  /* Configure the system clock */
  SystemClock_Config();

  /* Initialize all configured peripherals */
  MX_GPIO_Init();
  MX_TIM1_Init();
  MX_TIM2_Init();
  MX_TIM4_Init();
  MX_TIM5_Init();
  MX_TIM7_Init();
  MX_TIM8_Init();
  MX_UART4_Init();
  MX_USART1_UART_Init();
  MX_USART3_UART_Init();
  MX_TIM3_Init();
  /* USER CODE BEGIN 2 */
  mode=0;
  motor_init();
  servo1_init();
  servo2_init();
  servo4_init();
  is_close1=is_close2=is_close3=is_close4=500;
  is_down=is_groundturn=is_shut=is_stopping=is_fetch=0;
  deviation=deviation_f=turn_target=check_flag=imu_check=0;
  deviation_s=100;
  targetspeed=550;
  lefttarget=righttarget=0;
  curvature=curv_error=0;
  total_distance=theta0=0;
  Rx_command='0';
  avoid_dir=turn_flag=stop_flag=0;
  avoid_comfirm=1;
  IS_FIRDT_CAPTURED=0;
  HAL_TIM_Base_Start(&htim4);
  HAL_TIM_Base_Start(&htim3);
  HAL_TIM_IC_Start_IT(&htim4,TIM_CHANNEL_1);
  HAL_TIM_IC_Start_IT(&htim4,TIM_CHANNEL_2);
  HAL_TIM_IC_Start_IT(&htim4,TIM_CHANNEL_3);
  HAL_TIM_IC_Start_IT(&htim4,TIM_CHANNEL_4);
  HAL_UART_Receive_IT(&huart1,(void *)&USART1_RXbuff,1);
  HAL_UART_Receive_IT(&huart4,&Rx_byte,sizeof(Rx_byte));
  HAL_GPIO_WritePin(GPIOB, GPIO_PIN_13,GPIO_PIN_SET);
  /* USER CODE END 2 */

  /* Infinite loop */
  /* USER CODE BEGIN WHILE */
  while (1)
  {
    /* USER CODE END WHILE */

    /* USER CODE BEGIN 3 */
  }
  /* USER CODE END 3 */
}

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
/* USER CODE BEGIN 4 */
void HAL_TIM_PeriodElapsedCallback(TIM_HandleTypeDef *htim)
{
	if(htim->Instance == TIM7&&(mode!=0))
	{
		if(mode==1){
			targetspeed=500;
			//spinspeed=300;
		}
		if(mode==2){
			if(is_fetch==0){
				targetspeed=120;
				//spinspeed=100;
			    if(deviation_f==99){spin(1);}
			    else if(deviation_f!=99){
			    	alongside(deviation_f-3);
                    if(deviation_s<=55){
                    	setspeed(0,0);
                    	stop_flag+=1;
                    	if(stop_flag==10){
                    	    fetchplace();
                    	    uint8_t  CO3AskBuffer[3]={0xa0,1,0xa1};
                    	    HAL_UART_Transmit_IT(&huart1, (uint8_t *)CO3AskBuffer, sizeof(CO3AskBuffer));
                    	    for(int i=0;i<18;i++)
                    	    {servo4_turn(42+i);}
                    	    stop_flag=0;
                    	}
                    }
			    }
			}
			else if(is_fetch==1){
				targetspeed=200;
				setspeed(targetspeed,0);
	            turn_flag+=1;
				if(turn_flag>=60){
				     setspeed(0,0);
				     stop_flag+=1;
				     if(stop_flag==10){
				          stop_flag=0;
				          turn_flag=0;
				     }
				}
			}
		}
		if(mode==3){
			targetspeed=460;
			alongside(deviation);
		}
		if(mode==4){
			targetspeed=320;
		    servo3_scan();
		    HAL_UART_Receive(&huart3,IMURxBuffer,22,40);
		    JY901_Process();
            if(is_groundturn==0&&is_stopping==0){avoidance();}
            else if(is_groundturn!=0&&is_stopping==0){
            	turn_flag+=1;
            	if(turn_flag<turn_target)
            	{spin(is_groundturn);}
            	else if(turn_flag==turn_target){
            		avoid_stop();
            	}
            	else if((turn_flag>turn_target)&&(turn_flag<=turn_target+4)){setspeed(targetspeed,0);}
            	else if(turn_flag>turn_target+4){
            		avoid_stop();
            		is_groundturn=0;
            		turn_flag=0;
            	}
            }
            else if(is_stopping==1){
            	stop_flag+=1;
            	setspeed(0,0);
            	if(stop_flag==8){
            	    is_stopping=0;
            	    stop_flag=0;
            	}
            }
		}
		if(mode==5){
			HAL_GPIO_WritePin(GPIOB, GPIO_PIN_13,GPIO_PIN_RESET);
			targetspeed=150;
			if(is_stopping==0){
			    if(is_fetch==1){
				    if(deviation_f==99){spin(1);}
				    else if(deviation_f!=99){
				    	alongside(deviation_f);
				    	if(deviation_s<=17){
				    		setspeed(0,0);
				    		stop_flag+=1;
				    		if(stop_flag==10){
				    			fetchplace();
				    			is_fetch=0;
				    			stop_flag=0;
				    		}
				    	}
				    }
			    }
			    else if(is_fetch==0){
			    	setspeed(0,0);
			    	mode=0;
			    }
			}
			else if(is_stopping==1){
				stop_flag+=1;
				setspeed(0,0);
				if(stop_flag==20){
				     is_stopping=0;
				     stop_flag=0;
				}
			}
		}
		leftfeedback = motor_leftfeedback();			//获取当前速度
		rightfeedback = motor_rightfeedback();
		int leftdifference = leftspeedPID(lefttarget,leftfeedback,&lefterror);//当前PWM数�?�加上增量式PID计算�???????????????????????????????????????????????�???????????????????????????????????????????????
		int rightdifference = rightspeedPID(righttarget,rightfeedback,&righterror);//当前PWM数�?�加上增量式PID计算�???????????????????????????????????????????????�???????????????????????????????????????????????
		leftspeed += leftdifference;
		rightspeed += rightdifference;
		//限制PWM占空比范围
		if(leftspeed>maxspeed){leftspeed = maxspeed;}
		if(leftspeed<-maxspeed){leftspeed = -maxspeed;}
		if(rightspeed>maxspeed){rightspeed = maxspeed;}
		if(rightspeed<-maxspeed){rightspeed = -maxspeed;}
		if(lefttarget == 0 && leftfeedback ==0){leftspeed = 0;}
		if(righttarget == 0 && rightfeedback ==0){rightspeed = 0;}
		//将PID处理后的目标速度写入系统
		motor_PWM(leftspeed,rightspeed);
	}
}
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

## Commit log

2024-07-01 literature review
    [0805.SLDPRT, 1040310811_USD1040310811.sldprt, 1206.SLDPRT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]
2024-07-05 driver and list
2024-07-05 change doc arc
    [0805.SLDPRT, 1040310811_USD1040310811.sldprt, 1206.SLDPRT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]
2024-07-06 ppt and model
    [20_bolts_1st.SLDPRT, 30_bolts_1st.SLDPRT, Foundation.SLDPRT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]
2024-07-10 upload without exe
    [0805.SLDPRT, 1040310811_USD1040310811.sldprt, 1206.SLDPRT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]
2024-07-11 change diagram and pin-design
    [引脚分配.xlsx]
2024-07-13 models update
    [0805.SLDPRT, 1040310811_USD1040310811.sldprt, 1206.SLDPRT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]
2024-07-17 final 3d models
    [1connectionF2F3(2).SLDPRT, 1connectionF2F3(2).STL, 1connectionF2F3(2).f3d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]
2024-07-17 pin assignment
    [引脚分配(1).xlsx]
2024-07-21 update code
    [引脚分配(3).xlsx]

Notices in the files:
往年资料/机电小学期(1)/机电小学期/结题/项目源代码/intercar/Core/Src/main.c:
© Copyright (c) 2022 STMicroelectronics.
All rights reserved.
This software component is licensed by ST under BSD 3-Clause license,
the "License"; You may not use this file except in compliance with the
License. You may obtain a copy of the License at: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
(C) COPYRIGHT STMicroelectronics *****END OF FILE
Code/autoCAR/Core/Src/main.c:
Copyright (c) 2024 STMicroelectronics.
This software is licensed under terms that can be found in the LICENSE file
